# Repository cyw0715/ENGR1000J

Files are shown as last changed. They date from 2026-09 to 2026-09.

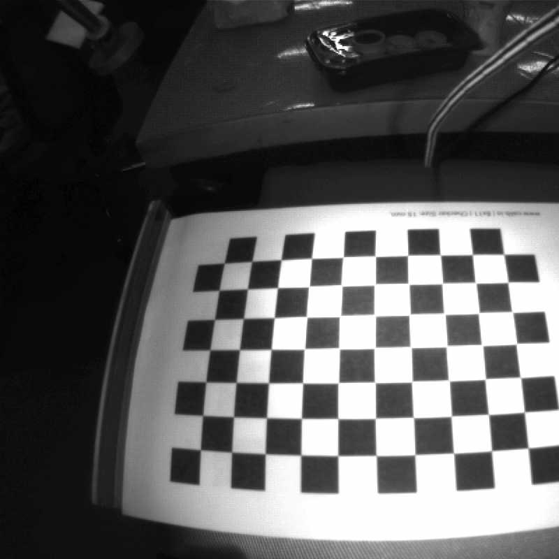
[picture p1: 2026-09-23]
project/wifi_test/calibration_runs/2026-08-04-fisheye-10x7-15mm/views/view_020.jpg

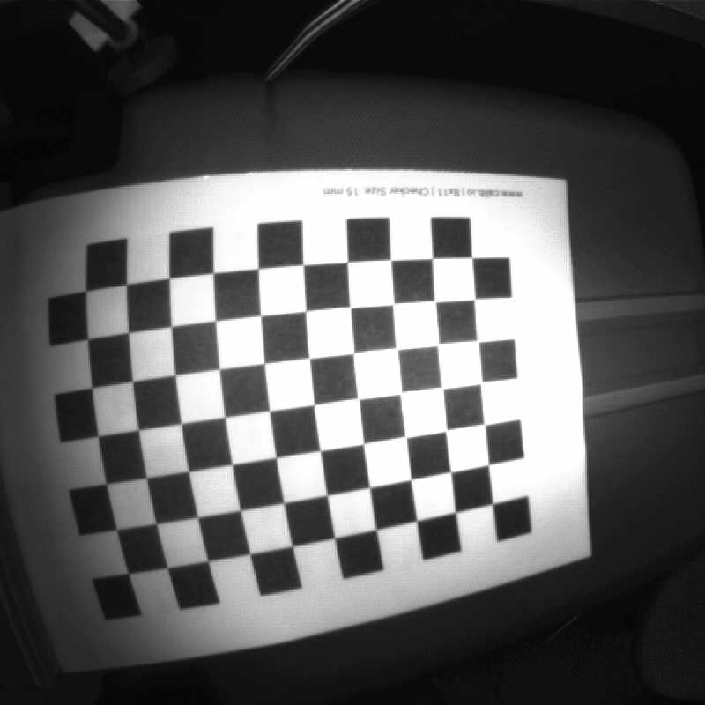
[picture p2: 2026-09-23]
project/wifi_test/calibration_runs/2026-08-04-fisheye-10x7-15mm/views/view_029.jpg

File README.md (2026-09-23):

# Mars Lander · Phase 2

四腿地形自适应火星降落器原型（ENGR1000 Phase 2）。下视相机 + IMU 做地形研究与姿态估计，四路直线推杆独立调节着陆平台。

## 仓库结构

| 路径 | 内容 |
|---|---|
| `project/` | 主工程：ESP32-P4 固件、Mega 执行器控制、PC 控制台、传感器测试 |
| `project/finalware/` | 当前部署固件快照与控制台（优先看这里） |
| `project/main/` | P4 主机相机/HTTP 固件 |
| `project/wifi_test/` | Wi-Fi 图传 / IMU 时间戳链路测试 |
| `project/usb_cdc_mega_test/` | Arduino Mega 四腿 VL53 闭环 + PS2 遥控 |
| `project/pc_viewer/` | Windows 控制台 `lander_console.py`、深度可视化 |
| `project/mechanical/` | 控制盒 CAD 生成脚本与 STEP/STL |
| `CAD/` | 外购件/结构 STEP 参考模型 |
| `docs/` | 交接文档、系统说明、接线总表、答辩 PPT、LaTeX |
| `experiments/` | MoGe 录屏深度实验 |
| `media/videos/` | 验证视频与控制台录屏（**不进 Git**，见 `.gitignore`） |

## 快速开始

### 固件（ESP-IDF v5.4+ / v5.5）

```bash
cd project          # 或 finalware/wifi_test 等子工程
idf.py set-target esp32p4
idf.py build
idf.py -p COMx flash monitor
```

### PC 控制台

```bash
cd project/pc_viewer
pip install -r requirements.txt
python lander_console.py
# 或 start_lander_console.bat
```

### Mega 执行器

Arduino IDE 打开 `project/usb_cdc_mega_test/faithful_remote_hybrid/faithful_remote_hybrid.ino` 烧录 Mega 2560。

## 安全边界（Stage 1）

- **Remote / CV Control**：遥控与 16 组预设，**不是**自动 CV 驱动腿。
- **IMU Control**：BNO085 姿态闭环，与 Remote 互斥。
- **相机 / 深度 / SR04 不得进入 Stage 1 腿指令路径**。
- `CV_CONTROL_VALIDATED = False` 仍为强制约束。

硬件映射、当前部署状态与调试步骤见 [`docs/HANDOVER.md`](docs/HANDOVER.md) 与 [`docs/PROJECT_SYSTEM_EXPLANATION.md`](docs/PROJECT_SYSTEM_EXPLANATION.md)。接线见 [`docs/火星降落器接线总表.md`](docs/火星降落器接线总表.md)。

## 硬件一览

| 层级 | 器件 | 职责 |
|---|---|---|
| 高层网关 | ESP32-P4 Function EV | 相机、BNO085、Wi-Fi/HTTP、USB Host、转发 Mega 指令 |
| 执行器 | Arduino Mega 2560 | 四路 VL53 位置闭环、PS2、电机、STOP/ESTOP |
| 传感器扩展 | TCA9548A | 四路同地址 VL53L1X |
| 惯性 | BNO085 | 姿态 |
| 相机 | OV5647 | 800×800 下视鱼眼 |
| 测距锚点 | HC-SR04 | 仅深度尺度研究输入 |

## 本地未入仓内容

验证视频、控制台录屏在 `media/videos/`；`build/`、`managed_components/`、Python venv、模型权重、Waveshare 示例包等可再生成，已由 `.gitignore` 排除。重新构建时 `idf.py` 会拉取 managed components。

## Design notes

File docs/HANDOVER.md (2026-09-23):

# Mars Lander Project — Engineering Handover

**Updated:** 2026-08-07 (CST)  
**Project root:** `E:\Chenyuewei\University\Freshman\summer\ENGR1000\p2\project`  
**Purpose:** preserve the hardware mapping, currently deployed firmware behavior, safety architecture, validation evidence, and next-stage commissioning sequence for the four-legged Mars landing platform.

---

## 1. System Purpose and Current Development Boundary

The project is a four-legged, terrain-adaptive Mars lander prototype. A downward-facing camera and an IMU support terrain research and attitude estimation; four independently controlled linear actuators provide landing-platform adjustment. The intended long-term behavior is to maintain a stable platform over unequal foot elevations.

The project is deliberately divided into two control stages:

```text
Stage 1 — deployed and controllable
  “CV Control” console mode = Remote owner, not automatic CV actuation.
  - faithful PS2 manual control and 16 source-program presets;
  - direct Console FL/FR/RL/RR absolute VL53 target entry;
  - Mega local four-leg position feedback and safety enforcement.

  “IMU Control” console mode = validated IMU attitude-control owner.
  - mutually exclusive with Remote;
  - retains the existing BNO085 attitude-control pathway.

Stage 2 — research only until separately validated
  Camera calibration → depth/terrain reconstruction → SR04 scale anchoring
  → four-foot relative elevation estimation → low-amplitude CV closed loop.

  `CV_CONTROL_VALIDATED = False` remains mandatory.
```

A computer-vision result, depth model, video stream, or SR04 reading must **not** enter a leg-command path in Stage 1.

---

## 2. Current Deployed Hardware State

### 2.1 Latest verified no-motion state

After the latest deployment and P4 recovery, repeated `/health` observations showed:

```text
P4 identity:  ESP32-P4 at 192.168.137.106
Mega state:   LOCKED
fault:        none
armed:        false
active:       false
target:       0,0,0,0
applied:      0,0,0,0
Mega RX line counter: increasing
```

Observed position feedback during the final no-motion verification was valid on all four channels:

```text
A1 = approximately 159–163 mm
A2 = approximately 94–96 mm
A3 = approximately 219–222 mm
A4 = approximately 143–145 mm
```

These values are installation-dependent measurements, not calibration constants.

### 2.2 Boards and links

| Layer | Hardware | Responsibility |
|---|---|---|
| High-level gateway | ESP32-P4 Function EV Board v1.3 | camera, BNO085, Wi-Fi/HTTP/TCP, USB Host, Mega command forwarding |
| Actuator controller | Arduino Mega 2560 + CH340 | four VL53 feedback loops, PS2 Remote behavior, motor outputs, STOP/ESTOP/watchdog |
| Sensor multiplexer | TCA9548A | isolates the four equal-address VL53L1X sensors |
| Inertial sensor | BNO085 | platform attitude for IMU mode |
| Camera | OV5647 | 800×800 downward-facing fisheye image stream |
| Range anchor | HC-SR04 on Mega | depth-scale research input only; never a Stage-1 leg target |
| PC application | Windows Console | mode selection, status display, Remote absolute-target entry, visualization and research tools |

### 2.3 USB identities

```text
P4 debug/programming interface:
  USB-Enhanced-SERIAL CH343, COM5
  VID:PID = 1A86:55D3

Mega downstream USB interface:
  CH340, VID:PID = 1A86:7523

Mega target signature:
  ATmega2560 = 1E9801
```

The P4 USB-A/OTG host connects to the Mega USB-B/CH340 device. P4-to-Mega commands must remain serialized through the single P4 transmit mutex.

---

## 3. Physical Four-Leg Mapping

The following mapping was established by bounded one-leg identification. It is authoritative.

```text
Mega A1 / TCA channel 0 / D22,D23,EN30 = RL (rear-left)
Mega A2 / TCA channel 1 / D24,D25,EN31 = RR (rear-right)
Mega A3 / TCA channel 2 / D26,D27,EN32 = FR (front-right)
Mega A4 / TCA channel 3 / D28,D29,EN33 = FL (front-left)

UI/solver order: FL, FR, RL, RR
Mega order:      A1, A2, A3, A4
Conversion:      FL→A4, FR→A3, RL→A1, RR→A2
```

Direction convention:

```text
EXTEND  → associated VL53 reading increases
RETRACT → associated VL53 reading decreases
```

Never pass a UI/solver array directly to Mega array positions without this remapping.

---

## 4. Mega Hybrid Firmware: Current Behavior

### 4.1 Source-faithful Remote controller

The hybrid firmware preserves the user-supplied Remote source as the behavioral reference. Immutable original reference:

```text
reference/111_1_original.ino
SHA256 = 1973c42c856dd61e18a53a6e8ca50d0e7503ce2a498bed8b9e75497d92f651f8
```

The deployed firmware preserves:

- PS2 wiring: DAT=D49, CMD=D47, CLK=D46, CS=D48;
- START toggle between `MANUAL` and `PRESET` selection modes;
- the original eight manual directional button mappings;
- the original 16 preset target vectors, values, and selection priority;
- three consecutive PS2 read failures before disconnect declaration;
- PS2 reconnect attempts every 2 s;
- preset tolerance of ±3 mm, two consecutive in-tolerance confirmations, and 30 s timeout.

The project-level automated contract compares the original and hybrid source for the presets, mappings, timing constants, reconnect behavior, and ownership boundary.

### 4.2 Ownership states

```text
LOCKED
  ALL_LOW; no PS2, Console, or IMU movement is permitted.

REMOTE_MANUAL / REMOTE_PRESET
  PS2 Remote is enabled after explicit `ARM REMOTE`.
  A Console absolute target temporarily suspends PS2 commands while it runs.

ARMED / ACTIVE
  IMU owner is enabled after explicit `ARM IMU`.
  PS2 Remote is suspended.

FAULT / ESTOP
  ALL_LOW; fault or emergency condition blocks normal movement.
```

Mode switching must stop the current owner before a new owner is armed. `STOP` and `ESTOP` bypass normal command authorization.

### 4.3 Active local safety functions

The following protections remain enabled and must not be removed during normal work:

```text
- four VL53 readings must be valid and fresh;
- maximum authoritative VL53 coordinate = 400 mm;
- current deployed lower coordinate = 0 mm;
- 2 s heartbeat timeout for host-owned Remote and IMU sessions;
- stale sensor timeout = 1200 ms;
- explicit STOP; latched ESTOP;
- hard all-output-low in LOCKED, FAULT, and ESTOP states;
- 120 ms break-before-make only when changing motor direction;
- non-blocking concurrent four-leg position regulation;
- full-group invalid target rejection, rather than silently altering an invalid command.
```

The lower coordinate was changed from 50 mm to 0 mm because a real valid sensor reading below 50 mm had caused `sensor_invalid_or_range`. This change does **not** remove sensor-validity, staleness, upper-limit, heartbeat, STOP, or ESTOP protection.

### 4.4 Remote protocol

```text
ARM REMOTE
HEARTBEAT <seq>
SET_REMOTE <seq> <FL> <FR> <RL> <RR>
STOP
ESTOP
STATUS
GET_DISTANCE
```

`SET_REMOTE` is in UI order `FL,FR,RL,RR` and uses direct absolute VL53 coordinates in the currently deployed range `[0,400]` mm. The Mega remaps this to physical A4,A3,A1,A2.

IMU commands remain separate:

```text
ARM IMU
HEARTBEAT <seq>
SET_DELTA <seq> <FL> <FR> <RL> <RR>
STOP
ESTOP
```

`SET_DELTA` is ARM-relative and still uses the bounded delta protocol. The Mega evaluates the resulting absolute target locally.

---

## 5. P4 Firmware and Network Interface

### 5.1 P4 production behavior

The ESP32-P4 production application provides:

```text
GET /board
  Board identity and current DHCP address.
  Required identity check: board == "ESP32-P4" and returned IP matches probe host.

GET /health
  P4 network, Mega, four-leg, SR04, Remote, and diagnostic status.

POST /cmd {"remote_arm": true}
  Forwards ARM REMOTE.

POST /cmd {"remote_set_absolute": true,
           "seq": N, "fl": ..., "fr": ..., "rl": ..., "rr": ...}
  Forwards SET_REMOTE with four absolute VL53 targets in [0,400] mm.

Existing IMU commands
  imu_arm, imu_set_delta, imu_heartbeat, imu_stop, imu_estop.
```

`/health.mega_imu` includes remote telemetry:

```text
remote_active
remote_source = ps2 | console | none
remote_preset = 0..15 or -1
remote_target_fl/fr/rl/rr
ps2_connected
remote_submode = manual | preset
```

### 5.2 Current network endpoints

| Endpoint | Function |
|---|---|
| TCP 5000 | JPEG frames: `[u32 little-endian length][JPEG bytes]` |
| TCP 5001 | JSONL latest BNO085 sample stream |
| HTTP `/board` | strict board identity and DHCP discovery |
| HTTP `/health` | P4/Mega/Remote/leg diagnostics |
| HTTP `/imu` | current IMU diagnostic state |

The current P4 address was last verified as `192.168.137.106`; do not hard-code it permanently. Use `/board` discovery.

### 5.3 CH340 session recovery

The production P4 firmware performs the proven sequence after CH340 opening:

```text
set_control_line_state(false, true)
wait 100 ms
set_control_line_state(true, true)
wait 6500 ms
begin Mega STATUS / GET_DISTANCE polling
```

It also reports `rx_byte_count` and `rx_line_count`. If the byte counter does not advance, the P4 is not receiving Mega application output; do not diagnose Console logic before resolving the transport/application layer.

---

## 6. Windows Console

Run the Console only with:

```text
pc_viewer\.venv_win\Scripts\python.exe
pc_viewer\.venv_win\Scripts\pythonw.exe
```

The UI has three modes:

```text
CV Control (Stage 1 Remote)
  - ARM button: ARM Remote
  - FL/FR/RL/RR absolute target entries: editable
  - Apply Remote target button: enabled
  - PS2 manual/preset remains the primary Remote interaction surface
  - CV, depth, video, and SR04 are preview/research-only inputs.

IMU Control
  - ARM button: ARM IMU
  - Remote target entries: read-only
  - Remote Apply button: disabled
  - P4 TCP 5001 attitude stream is required by the IMU loop itself.

Locked
  - Remote entries: read-only
  - Remote Apply: disabled
  - ARM: disabled.
```

Remote command availability does not depend on SR04, camera TCP 5000, depth model load, CV capture count, CV candidate age, or `CV_CONTROL_VALIDATED`. It does depend on P4/Mega communication, valid four-leg feedback, owner state, and hard safety status.

Before launching a new Console instance, close stale `lander_console.py` processes. Two stale processes previously re-armed a Remote session after P4 recovery; this was resolved by issuing `STOP`, confirming `LOCKED`, and closing both processes.

---

## 7. Camera, IMU, SR04, and Vision Research

### 7.1 Camera calibration

The replacement camera is an 800×800 fisheye camera. The accepted calibration result is:

```text
Calibration set: 36 views
Board: 11×8 squares, 10×7 inner corners, 15 mm square size
RMS reprojection error: 0.717 px
Mean reprojection error: 0.562 px
Maximum reprojection error: 1.947 px
Accepted for geometry: true

K ≈ [[638.075, 0, 613.459],
     [0, 636.365, 452.471],
     [0,   0,       1   ]]
D ≈ [-0.06099, 0.09688, -0.14361, 0.06626]
```

Results are stored under:

```text
wifi_test/calibration_runs/2026-08-04-fisheye-10x7-15mm/
```

External-pose collection reached 20/20 usable samples:

```text
Mean reprojection error: 0.345 px
Maximum reprojection error: 0.366 px
Camera-to-board-plane distance: 354.73 mm
Optical-axis inclination: 3.66 degrees
```

The platform front/back 180° ambiguity remains unresolved. Do not use this pose for control orientation until that ambiguity is eliminated.

### 7.2 SR04 role

The HC-SR04 is wired to Mega:

```text
TRIG = D53
ECHO = D52 / PB1 / PCINT1
```

It is a scale anchor for depth research only. A stable window requires recent independent samples, a median, minimum count, and spread/MAD checks. Its accepted use is:

\[
\mathrm{scale}=
\frac{\mathrm{stable\ SR04\ median}}
{\mathrm{model\ depth\ median\ in\ principal-point\ ROI}},
\qquad
D_{\mathrm{corrected}}=\mathrm{scale}\cdot D_{\mathrm{model}}.
\]

If the SR04 stability test fails, use `metric_source=model_only`; do not reuse an old scale anchor. SR04 distance must never be converted directly into a common leg extension.

### 7.3 CV terrain semantics

Future CV control may use only relative terrain differences across the four predicted foot regions:

\[
\delta_i=L_i-\frac{1}{4}\sum_{j=1}^{4}L_j,
\qquad
\sum_i\delta_i=0.
\]

The current research constraints are:

```text
- each relative correction limited to ±100 mm;
- boundary handling uses one common scale factor, never independent clipping;
- a common terrain-height offset must not change the command;
- NaN/unobservable foot regions reject the plan;
- vision output remains preview-only until physical plane/step validation is complete.
```

A real scale-correction script processed 16 valid anchored frames with an observed scale approximately 0.526–0.607, but the intended 30-frame acquisition was not completed because TCP 5000 permits one client. Do not claim complete 30-frame acceptance yet.

---

## 8. Firmware Artifacts and Build Evidence

### Mega hybrid source

```text
usb_cdc_mega_test/faithful_remote_hybrid/
  faithful_remote_hybrid/faithful_remote_hybrid.ino
  reference/111_1_original.ino
  test_faithful_remote_contract.py
```

Latest range-0-to-400 Mega application image:

```text
SHA256 = da51089c186d3912c7e228fabce591849e693fdf4ee7221c5b981866abb54076
ATmega2560 application payload = 22,380 bytes
Pages written = 88
Verification = every page read back after write
```

### P4 production source

```text
wifi_test/main/main.c
wifi_test/main/mega_sr04.c
wifi_test/main/mega_sr04.h
```

Current build passed ESP-IDF v5.4 and generated `wifi_test.bin` with approximately 21% free application partition space. P4 flashing verified the bootloader, partition table, and application image with `Hash of data verified` for each region.

### Tests last run successfully

```text
PC Console + terrain/control suite: 124 tests
Faithful Remote source contract: 9 tests
P4 protocol contract: 12 tests
Legacy Mega controller contract: 10 tests
```

---

## 9. Safe Commissioning Sequence

Use the following sequence after any firmware, cable, or mechanical change:

1. Confirm no stale Console process is running.
2. Read `/board`; verify `board=ESP32-P4` and the current DHCP address.
3. Read `/health` repeatedly. Require increasing Mega RX counters, `LOCKED`, `fault=none`, valid A1--A4, zero target, and zero applied values.
4. If any fault occurs, send `STOP`; do not arm around a fault.
5. For a first Remote test, arm Remote with no button pressed and no Console target.
6. Confirm `REMOTE_MANUAL` or `REMOTE_PRESET`, `remote_active=false`, and no motor output.
7. Perform a same-current-value Console target or a verified no-motion preset selection before requesting motion.
8. Test one small 2--3 mm change at a time; then STOP and verify `LOCKED`.
9. Commission PS2 manual and preset behavior separately from IMU behavior.
10. Commission IMU only after Remote STOP, explicit IMU ARM, and live TCP 5001 attitude verification.

Never start a movement experiment by testing all four legs, a large preset, or an unverified CV output.

---

## 10. Open Work

1. Diagnose the full PS2 electrical connection if `ps2_connected=false`; a disconnected Remote must remain harmless.
2. Complete Stage-1 physical verification of selected source presets and direct Console absolute targets using small, supervised movements.
3. Re-confirm the IMU closed-loop behavior after the Hybrid Mega firmware change; preserve the previously accepted installation transform and PID semantics.
4. Resolve the external-pose front/back ambiguity.
5. Complete physical flat-plane and 10/20/30/50 mm step validation for the depth pipeline.
6. Complete a dedicated 30-frame SR04-anchored depth acquisition after releasing TCP 5000 from other clients.
7. Do not enable automatic CV leg actuation until all calibration, terrain, relative-delta, and staged hardware acceptance gates are documented as passed.

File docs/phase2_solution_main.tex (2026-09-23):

\documentclass{engr1000j-s2}

\usepackage{tabularx}
\usepackage{lastpage}
\usepackage{listings}
\usepackage{amsmath}
\usepackage{amssymb}
\usepackage{enumitem}

\usepackage{tocloft}

% spacing between numbering and title
\renewcommand{\cftsecaftersnum}{\hspace{1em}}
\renewcommand{\cftsubsecaftersnum}{\hspace{1em}}
\renewcommand{\cftsubsubsecaftersnum}{\hspace{1em}}

% indentation for hierarchy
\setlength{\cftsecindent}{0em}
\setlength{\cftsubsecindent}{2em}
\setlength{\cftsubsubsecindent}{4em}

% dot spacing
\renewcommand{\cftdotsep}{1}

\hypersetup{
  hidelinks,
  pdftitle={Mars Explorer Phase Two Report},
  pdfauthor={Group 5: Six Gentlemen}
}

\lstdefinestyle{appendixcode}{
  basicstyle=\ttfamily\scriptsize,
  breaklines=true,
  breakatwhitespace=false,
  columns=fullflexible,
  keepspaces=true,
  showstringspaces=false,
  frame=single,
  xleftmargin=0pt,
  xrightmargin=0pt
}

\newcommand{\statusdone}{\textbf{Completed}}
\newcommand{\statusprogress}{\textbf{In Progress}}
\newcommand{\statusplanned}{\textbf{Planned}}

\begin{document}

  
  \newline
  \newline
  \textbf{\Large ENGR1000J Introduction to Engineering, Summer 2026}\\[0.5em]
  \textbf{{\Large 2026.08.08}}

  \begin{center}
    \begin{minipage}{0.45\textwidth}
      
    \end{minipage}\hfill
    \begin{minipage}{0.45\textwidth}
      \textbf{\Large Group 5: Six Gentlemen}
    \end{minipage}\\[0.2em]
  \end{center}

  \noindent
  {\color{gray!30}\rule{\textwidth}{0.1pt}}

  {\Huge Self-Stabilizing Landing Platform}

  \begin{center}
    
  \end{center}

  \hspace{1em}

  {\Large
  Chen Yuewei\par\vspace{-10pt}
  Sun Andong\par\vspace{-10pt}
  Sun Yongjian\par\vspace{-10pt}
  Cui Yukun\par\vspace{-10pt}
  Ding Junyuan\par\vspace{-10pt}
  Ge Chengzhi\par\vspace{-10pt}
  }

  \newpage
  \pagestyle{mystyle}

 \section{Abstract}
  \phantomsection

Reliable landing is essential for planetary exploration because an inclined landing platform may reduce antenna alignment, decrease solar-panel efficiency, and create unstable conditions for rover deployment. Rough and uneven Martian terrain can cause the landing legs to contact the surface at different heights, leaving the platform tilted even after a safe touchdown. This project aimed to develop a self-stabilizing landing platform that could actively correct its attitude after landing and provide a more stable base for subsequent mission operations. The proposed prototype used a four-leg aluminum structure with independently adjustable linear actuators. An OV5647 camera was used for terrain imaging, a BNO085 inertial measurement unit measured the platform attitude, and four VL53L0X time-of-flight sensors monitored the extension of the landing legs. An ESP32-P4 and ESP-C6 processing unit calculated the required leg-length adjustments, while an Arduino Mega 2560 controlled the actuators through the motor-driving system. After touchdown, the platform measured its inclination and leg positions, determined which legs required extension or retraction, and repeatedly performed sensing, calculation, and actuation until the residual tilt was reduced. Physical testing showed that the prototype achieved an average final tilt angle of \(2.61^\circ\), below the design limit of \(5.0^\circ\). It also maintained a descent speed of \(5.2~\mathrm{cm/s}\), supported a payload of at least \(16~\mathrm{kg}\), and completed 19 of 20 trials successfully, corresponding to a success rate of \(95\%\). These results demonstrate that independent leg adjustment combined with closed-loop feedback can effectively reduce terrain-induced platform inclination. Although the current prototype was tested only under Earth-based laboratory conditions, the project verified the feasibility of active post-touchdown leveling. Further development of this technology could improve the reliability of planetary landers, protect onboard instruments, support safer rover deployment, and enable future exploration missions to operate on a wider range of uneven terrain.

\hspace{1em}

\section{Acknowledgments}
\phantomsection

The team would like to thank the ENGR1000J instructors, teaching assistants, and course support staff for their guidance throughout Phase Two. Their lectures, laboratory sessions, office-hour feedback, and project regulations provided the technical framework for the design, fabrication, testing, and reporting process.

The team also acknowledges the use of Codex and Gemini as writing and formatting assistance tools, and Image2 and Nano Banana as AI image-generation tools. Codex and Gemini were used to help organize report sections, refine English wording, structure LaTeX tables, and check whether report requirements were clearly represented. Image2 and Nano Banana were used to support image generation for report visuals. All technical claims, design descriptions, material choices, generated images, and test results were reviewed and confirmed by the team before inclusion in the final report.

  \newpage
  \tableofcontents
  \thispagestyle{mystyle}
  \newpage

\section{Problem}
\label{sec:problem}

The surface of Mars presents a major challenge to the safe landing and subsequent operation of robotic exploration systems. Martian terrain contains rocks, slopes, depressions, loose soil, and other irregular surface features. Observations from NASA's surface missions show that steep slopes, rocks, and sand can significantly restrict robotic operations and require mission teams to avoid hazardous regions \cite{nasa_curiosity_climb}. At the scale of a landing platform, these irregularities may cause its supporting legs to contact the surface at different elevations. Consequently, a spacecraft may complete its descent without structural damage but remain tilted after touchdown.

Platform inclination can affect several important mission functions. Communication antennas and solar panels depend on suitable orientation to achieve effective signal transmission and power generation. A tilted deck may also reduce the stability of scientific instruments and create unsafe conditions for rover release. These consequences are especially important because planetary missions operate with limited energy, restricted communication opportunities, and little possibility of physical repair. A landing attitude that would be only a minor inconvenience on Earth may therefore reduce scientific return or threaten the operation of an entire Mars mission.

Terrain slope is already treated as an important engineering constraint during landing-site evaluation. NASA's engineering guidance for the Mars Science Laboratory classified surface slopes below \(5^\circ\) as low, slopes between \(5^\circ\) and \(15^\circ\) as moderate, and slopes above \(15^\circ\) as high \cite{msl_engineering_guide}. This classification demonstrates that relatively small differences in surface geometry can influence landing and surface-operation decisions. However, orbital images and pre-landing measurements cannot always identify every rock or height variation beneath an individual landing leg. Even a region considered generally safe may therefore produce unequal contact conditions at the final touchdown points.

Previous engineering approaches have addressed parts of this problem. Passive landing structures and shock absorbers can reduce touchdown impact and protect the lander from excessive loads \cite{pham2013}. More recent missions have also used hazard-detection and terrain-relative navigation technologies. For example, the Mars 2020 landing system compared descent images with stored terrain maps and could redirect the vehicle toward a safer area \cite{nasa_trn2020}. Lidar-based hazard-detection systems have similarly been investigated for planetary landing applications \cite{huang2024}. These methods improve landing safety by reducing impact or avoiding major hazards before touchdown.

Nevertheless, these approaches do not completely address the remaining static inclination after ground contact. Passive dampers absorb energy but do not normally correct unequal final support heights. Pre-landing hazard avoidance selects a safer region, but its effectiveness is limited by sensing resolution, landing-position uncertainty, and small local surface features. The unresolved problem therefore affects spacecraft designers, mission operators, scientific payload teams, and rover-deployment systems: a lander may survive touchdown but still lack a sufficiently stable and level operating platform.

\medskip
\noindent\textbf{In summary, the most important unresolved problems are:}

\begin{enumerate}
    \item Unequal landing-leg contact heights caused by rocks, slopes, and surface depressions;
    \item Residual platform tilt that may reduce communication, power generation, instrument stability, and rover-deployment safety;
    \item Limited ability of passive landing systems to correct static inclination after touchdown;
    \item Incomplete protection from small terrain variations despite pre-landing hazard detection and landing-site selection.
\end{enumerate}

\section{Needs}
\label{sec:needs}

To address the problems caused by uneven landing-leg contact and residual platform tilt, the landing platform requires an active system that can detect its condition after touchdown and respond to local terrain variations. The system must not depend only on passive shock absorption or pre-landing hazard avoidance, because these methods cannot fully compensate for small differences in the final contact heights of the landing legs. Instead, the platform must combine sensing, computation, mechanical adjustment, and feedback control in one integrated process.

The principal engineering needs of the project are:

\begin{itemize}
    \item \textbf{Terrain and attitude sensing methods to detect uneven ground contact, local height differences, and residual platform inclination after touchdown.}

    \item \textbf{Four independently adjustable landing legs capable of extending or retracting to compensate for different ground-contact heights.}

    \item \textbf{A closed-loop control method that repeatedly measures the platform attitude, calculates the required leg-length changes, and commands the actuators until the tilt is reduced below the specified limit.}

    \item \textbf{A sufficiently strong and stable supporting structure that can carry a payload of at least \(15~\mathrm{kg}\) while maintaining reliable actuator motion and sensor alignment.}

    \item \textbf{System integration and experimental validation methods that evaluate tilt reduction, descent speed, payload capacity, and leveling success rate under different uneven-terrain conditions.}
\end{itemize}

To satisfy the sensing requirement, the platform needs both environmental and internal measurements. Terrain imaging is required to observe the landing surface, while an inertial measurement unit is needed to determine the orientation of the main platform. Additional distance sensors are required to monitor the extension of each adjustable leg. In the proposed system, these functions are provided by an OV5647 camera, a BNO085 inertial measurement unit, and four VL53L0X time-of-flight sensors.

The mechanical system requires four miniature linear actuators so that each landing point can be adjusted independently. Independent control is necessary because the height error at one leg may differ from that at the other three legs. The actuators must also provide sufficient force to support the platform and its payload without uncontrolled retraction or excessive structural deformation.

A processing and control system is required to convert sensor measurements into physical corrections. The ESP32-P4 and ESP-C6 processing unit must analyze the sensing information and calculate the required change in each leg length. The Arduino Mega 2560 must then control the actuators through the motor-driving system. After each movement, the platform attitude must be measured again so that the remaining error can be corrected.

Finally, the completed system must be tested against measurable performance requirements. The final tilt angle should be below \(5.0^\circ\), the payload capacity should be at least \(15~\mathrm{kg}\), the descent speed should be approximately \(5~\mathrm{cm/s}\), and the landing and leveling process should achieve a success rate of at least \(90\%\). Meeting these needs would provide a stable post-touchdown platform for communication equipment, solar panels, scientific instruments, and rover-deployment systems.

\newpage

\section{Solution}

\begin{enumerate}
    \item \textbf{A four-corner adaptive landing platform} with one independently controlled linear actuator at each landing corner, allowing the support plane to be adjusted after touchdown on uneven terrain.
    \item \textbf{A distributed sensing and control architecture} combining four VL53L1X position sensors, a TCA9548A multiplexer, an Arduino Mega 2560 real-time actuator controller, an ESP32-P4 communication gateway, a BNO085 IMU, an OV5647 camera, and an HC-SR04 range sensor.
    \item \textbf{A completed Stage-1 terrain-elevation control mode} that converts a calibrated elevation map of the four landing-foot regions into coordinated differential leg-length targets.
    \item \textbf{A mutually exclusive IMU attitude-control mode} that uses measured platform roll and pitch to generate coordinated differential leg corrections.
    \item \textbf{A layered safety architecture} incorporating explicit arming, command ownership, local position feedback, sensor freshness checks, heartbeat supervision, STOP, ESTOP, travel limits, and all-output-low fault behavior.
\end{enumerate}

The proposed solution is a terrain-adaptive Mars landing platform intended to reduce post-touchdown tilt when the four landing feet contact terrain of unequal elevation. The platform is approximately $200\,\mathrm{mm}\times200\,\mathrm{mm}$, with one independently driven linear actuator at each corner. A rigid landing configuration transfers local terrain height differences directly into platform roll and pitch; consequently, it can degrade payload stability, camera pointing, and the available actuator travel margin. The proposed system instead treats the four leg positions as independently regulated variables and uses their coordinated motion to alter the support plane formed by the landing feet.

The physical actuators are designated FL, FR, RL, and RR. Their mapping to the Mega controller is fixed as
\[
\mathrm{FL}\rightarrow A4,\qquad
\mathrm{FR}\rightarrow A3,\qquad
\mathrm{RL}\rightarrow A1,\qquad
\mathrm{RR}\rightarrow A2.
\]
This mapping is essential because the geometric solver uses the order FL--FR--RL--RR whereas the electrical controller uses A1--A4. Each actuator has a dedicated VL53L1X time-of-flight sensor. The four equal-address sensors are isolated through a TCA9548A I$^2$C multiplexer, enabling the Mega to acquire independent position feedback for every leg. The verified direction convention is
\[
\text{EXTEND}\Rightarrow d_i\ \text{increases},
\qquad
\text{RETRACT}\Rightarrow d_i\ \text{decreases},
\]
where $d_i$ is the local VL53 coordinate of actuator $i$.

For every requested target $d_{i,\mathrm{target}}$, the Mega calculates the local position error
\[
e_i=d_{i,\mathrm{target}}-d_{i,\mathrm{measured}}.
\]
A positive error commands extension and a negative error commands retraction. The actuator output is disabled after the target is reached within the specified tolerance. This local feedback loop is executed on the Mega rather than on the PC, so a delayed Wi-Fi packet, a frozen camera frame, or a Windows application failure cannot remove the fundamental position-feedback and stop functions. Direction reversal includes a $120\,\mathrm{ms}$ break-before-make interval, preventing opposing motor-drive states from being applied simultaneously.

\subsection*{Stage-1 Elevation-Map Landing-Leg Control}

Stage~1 implements the completed terrain-adaptive landing controller. The OV5647 fisheye camera provides an elevation map of the landing area, while the calibrated camera geometry projects the four predicted foot-contact regions into that map. The controller samples a robust local elevation $h_i$ for each foot region $i\in\{\mathrm{FL},\mathrm{FR},\mathrm{RL},\mathrm{RR}\}$. Invalid pixels, regions outside the valid depth field, and inconsistent local estimates are rejected before target generation. The HC-SR04 provides the global millimetre scale anchor for the reconstructed elevation field; it is not used as an independent per-leg height sensor.

The controller removes the common elevation component so that it commands only support-plane compensation rather than an arbitrary collective translation. With
\[
\bar h=\frac{1}{4}\sum_{j=1}^{4}h_j,
\qquad
\Delta h_i=h_i-\bar h,
\qquad
\sum_{i=1}^{4}\Delta h_i=0,
\]
the required leg-length correction is generated as
\[
L_{i,\mathrm{target}}=L_{i,0}+k_h\Delta h_i,
\]
where $L_{i,0}$ is the established landing reference length and $k_h$ is the calibrated sign and scale factor relating terrain elevation to actuator length. Thus, a relative terrain-height change modifies the landing-leg configuration while preserving the mean commanded length. The Console and P4 remap the geometric order FL--FR--RL--RR to the fixed Mega order A4--A3--A1--A2 before sending the four targets to the common Mega position-control routine.

Each candidate correction is constrained to the approved differential travel envelope $|\Delta L_i|\leq100\,\mathrm{mm}$. If a candidate would cross a leg travel boundary, all four differential corrections are reduced by one common scale factor rather than clipping individual legs. This preserves the intended support-plane orientation and the zero-sum condition. The Mega then closes the four local VL53L1X feedback loops independently; it stops each output on target, stale feedback, invalid feedback, timeout, STOP, or ESTOP. Consequently, the elevation map selects the coordinated target geometry, while the hardware-proven Mega loop remains responsible for final actuator positioning and non-motion safety.

The Stage-1 result is a complete path from camera-derived terrain elevations to bounded four-leg target lengths. It compensates the relative elevation differences across the four foot regions and therefore reduces predicted post-touchdown roll and pitch without treating the absolute terrain range as an individual leg command.

\subsection*{Stage-2 IMU Attitude-Control Solution}

The second control owner is the IMU mode. It is mutually exclusive with Stage-1 elevation-map control: switching modes first issues STOP to the active owner, clears pending targets, and requires a new explicit ARM action. The BNO085 provides platform attitude. Its installation-frame transformation converts the sensor reading into platform roll and pitch, which are then used to generate coordinated differential leg corrections. The target condition is approximately
\[
|\phi_{\mathrm{platform}}|\leq1^\circ,
\qquad
|\theta_{\mathrm{platform}}|\leq1^\circ.
\]

IMU control changes opposing corners in opposite directions where appropriate, producing a change in support-plane orientation rather than an arbitrary common vertical displacement. The existing IMU pathway retains its validated outer attitude correction, inner position regulation, bounded target update rate, and Mega-side local safety checks. It is therefore an automatic leveling mode based on measured inertial state, complementary to the completed Stage-1 terrain-elevation controller.

\subsection*{Safety and Communication Solution}

The lander uses a layered authority model. The PC Console provides user interaction, status visualization, and high-level mode requests. The ESP32-P4 handles Wi-Fi, the camera and IMU interfaces, USB Host communication, and a single serialized command path to the Mega CH340 interface. The Mega remains the actuator safety authority. It implements the states \texttt{LOCKED}, \texttt{STAGE1\_ELEVATION}, \texttt{IMU\_ACTIVE}, \texttt{FAULT}, and \texttt{ESTOP}.

In \texttt{LOCKED}, \texttt{FAULT}, and \texttt{ESTOP}, all motor enable and direction outputs are low. Host-owned sessions require a heartbeat; if no valid heartbeat arrives within two seconds, the Mega stops the outputs. Each VL53 reading must be valid and newer than the sensor freshness threshold. The controller also rejects targets above the $400\,\mathrm{mm}$ upper limit. STOP and ESTOP bypass normal motion authorization. Consequently, the proposed lander does not rely on correct PC software, continuous Wi-Fi, or valid computer vision to preserve a safe non-motion state.

\newpage

\section{Objectives}

The seven objectives below correspond one-to-one with Tasks~1--7 in Section~\ref{sec:tasks}. Each objective defines the intended deliverable and the verification focus of its corresponding task.

\textbf{Objective 1 (Task 1): Design and fabricate the aluminum frame.}

Develop a rigid 2020L aluminum-extrusion support frame that provides the required height, stiffness, and attachment points for the four-point suspension and landing-platform test system. Verify that the frame can safely support the platform, payload, winch assemblies, and associated wiring without unacceptable deformation or loss of alignment.

\textbf{Objective 2 (Task 2): Design and control the four-winch descent system.}

Design the four-motor winch mechanism and its L298N-based control system so that the suspended platform can descend and be retrieved with coordinated cable motion. Establish start/stop, direction-reversal, braking, and individual PWM compensation behavior, then verify a controlled descent speed of approximately $5~\mathrm{cm/s}$.

\textbf{Objective 3 (Task 3): Design and fabricate the adjustable landing platform.}

Build the $300~\mathrm{mm}\times300~\mathrm{mm}$ acrylic landing platform, four angled linear-actuator legs, reinforced brackets, articulated feet, and leg-displacement sensing mounts. The completed structure must provide independent FL, FR, RL, and RR adjustment, preserve the geometric-to-electrical leg mapping, and support at least $15~\mathrm{kg}$ while maintaining mechanical stability and sensor alignment.

\textbf{Objective 4 (Task 4): Implement computer-vision-based terrain detection.}

Use the calibrated OV5647 fisheye camera to construct an elevation map of the landing area and estimate robust relative elevations in the four projected foot-contact regions. Use the HC-SR04 only as a global millimetre scale anchor, reject invalid terrain regions, and transform valid relative elevations into a zero-sum, travel-bounded four-leg compensation vector rather than four independent absolute-height commands.

\textbf{Objective 5 (Task 5): Implement IMU-based automatic leveling.}

Use the BNO085 to measure platform roll and pitch after touchdown and implement a mutually exclusive automatic leveling mode that commands coordinated differential leg corrections. Verify that the controller uses bounded updates, the Mega local position-feedback loop, and STOP/ESTOP protection to reduce residual platform tilt toward the $5.0^\circ$ design limit without arbitrary collective leg motion.

\textbf{Objective 6 (Task 6): Design and fabricate repeatable simulated terrain.}

Create laboratory terrain fixtures with known slopes, steps, and unequal landing-foot elevations that reproduce the local-height disturbances expected during touchdown. The terrain must be stable, repeatable, compatible with the articulated feet, and sufficiently varied to evaluate both elevation-map compensation and IMU-based leveling.

\textbf{Objective 7 (Task 7): Integrate and validate the complete landing system.}

Integrate the aluminum frame, winch system, landing platform, terrain sensing, IMU, controllers, communication path, and simulated terrain into one testable prototype. Validate system-level performance through repeated landing trials, including final tilt, descent speed, payload capacity, sensor and actuator safety behavior, and a leveling success rate of at least $90\%$.

\newpage

\section{Tasks}
\label{sec:tasks}

\subsection{Overview of Project Tasks and Workflow}

\newpage

\subsection{Task 1: Aluminum Frame Design and Fabrication}

\subsubsection{Structural Requirement Analysis}

\subsubsection{Aluminum Frame Design and Fabrication}

\newpage

\subsection{Task 2: Winch Motor System Design and Control}

\subsubsection{Winch Mechanism Design}

\subsubsection{Winch Motor Control}

\newpage

\subsection{Task 3: Landing Platform Design and Fabrication}

\subsubsection{Platform Structural Design and Assembly}

The landing platform was designed as a lightweight and modular mechanical structure that integrates four independently adjustable landing legs, the electronic control hardware, and the interfaces required for the external descent system. The main platform was fabricated from a \(5~\mathrm{mm}\)-thick acrylic plate with an overall envelope of \(300~\mathrm{mm}\times300~\mathrm{mm}\). Rather than using the complete square plate, the four corner regions were removed, leaving a \(200~\mathrm{mm}\times200~\mathrm{mm}\) central area with four \(100~\mathrm{mm}\)-wide extensions centered on its sides. These extensions provided dedicated locations for the suspension eye nuts and allowed the four suspension points to be aligned with the winch system mounted on the external aluminum frame.

The acrylic plate also served as a modular mounting board for the electronic components. A regular array of \(4~\mathrm{mm}\)-diameter mounting holes was fabricated at \(20~\mathrm{mm}\) intervals across the usable platform area. The resulting perforated-board structure allowed the Arduino, sensor interfaces, motor-control electronics, wiring, and other modules to be secured using cable ties without requiring a dedicated mounting hole pattern for every component. This arrangement simplified assembly and allowed the positions of individual modules to be adjusted during system integration. It also made components easier to remove or replace when modifications were required.

Four linear actuators formed the adjustable landing legs. Each actuator was mounted at one corner of the acrylic platform using a customized 3D-printed PLA bracket. The mounting geometry was modeled in SolidWorks so that each actuator was installed at an angle of \(30^\circ\) from the vertical direction. Integrating this angle directly into the bracket geometry ensured that the four legs could be assembled with a consistent orientation without manually setting the angle during installation. The outward inclination also increased the spacing between the four ground-contact points relative to the size of the central platform while providing sufficient clearance for actuator extension.

Additional customized PLA components were designed for the displacement-measurement system installed on each landing leg. A VL53L0X Time-of-Flight sensor and a matte target plate were mounted on the two relatively moving sections of each actuator using separate 3D-printed holders. As the actuator extended or retracted, the relative distance between the sensor and the target changed accordingly. The target plate provided a defined measurement surface, allowing the measured distance to represent the change in actuator extension. This mechanical arrangement therefore integrated the leg-length measurement hardware directly into the actuator structure without modifying the actuator itself.

Each actuator was also equipped with a 3D-printed articulated foot at its lower end. The foot was connected through a single-axis rotating joint rather than being rigidly fixed to the actuator rod. This allowed the contact surface to rotate relative to the leg and accommodate different local surface angles when the platform landed on uneven terrain. The articulated connection reduced the requirement for the actuator axis to remain perpendicular to the terrain at every landing point and provided a larger and more adaptable contact surface than the actuator rod alone.

The structural design of the actuator brackets was revised during fabrication after an initial load-bearing failure. The first version of the PLA actuator mounting bracket was printed with a \(15\%\) infill ratio. Because this bracket transferred the landing-leg load directly to the acrylic platform, the relatively low-density printed structure was insufficient for the required load and fractured during testing. The bracket was subsequently thickened and reprinted with \(100\%\) infill. The reinforced version was then used for the final assembly. This modification demonstrated that the actuator mounting brackets were load-bearing structural components and therefore required substantially greater strength than non-load-bearing sensor holders.

The complete structure was assembled in stages. First, the external 2020L aluminum extrusion frame was constructed and the four-motor winch system was installed at the top of the frame. In parallel, the four linear actuators and their reinforced 3D-printed mounting brackets were attached to the corners of the acrylic platform. The sensor holders, matte target plates, and articulated feet were then installed on the corresponding sections of each landing leg. The electronic modules were positioned on the perforated acrylic plate and secured through the mounting holes using cable ties. Finally, the suspension eye nuts on the four side extensions of the platform were connected to the fishing-line suspension system and aligned with the four winches above. This modular assembly procedure allowed the landing platform and the external descent frame to be constructed and tested separately before being integrated into the complete landing system.

\newpage

\subsection{Task 4: Computer Vision Based Terrain Detection}
\label{task:cv-terrain}

\subsubsection{Fisheye Calibration and Platform Coordinate System}

Task~4 developed the terrain-observation path used to estimate the relative elevation at the four expected landing-foot regions. The downward-looking OV5647 camera operated at $800\times800$ pixels. Because its fisheye lens introduces substantial distortion away from the image center, the camera was calibrated with an $11\times8$ square checkerboard containing $10\times7$ inner corners and $15~\mathrm{mm}$ squares. Thirty-six valid calibration views were retained. The OpenCV fisheye solution achieved a mean reprojection error of $0.562$ pixels and an RMS error of $0.717$ pixels, providing the intrinsic matrix and distortion coefficients used in terrain projection.

A camera-to-platform transformation was then measured with the checkerboard fixed in the platform coordinate frame. Twenty pose samples established the rigid transformation. The camera center was approximately $354.7~\mathrm{mm}$ above the board reference plane, and the optical-axis tilt relative to the board normal was $3.66^\circ$. An asymmetric front marker verified the axis convention: platform $+x$ points right, platform $+y$ points forward, and platform $+z$ points upward. This verification is essential because a geometrically valid image measurement must still be associated with the correct physical landing leg.

\subsubsection{Depth-Map Construction and Scale Anchoring}

The PC receives the downward camera stream, rejects frames with insufficient scene structure, and estimates dense depth maps from accepted images. A metric-depth estimate and a relative-depth estimate are fused. To reduce sensitivity to JPEG artifacts, motion blur, and isolated inference errors, the software captures thirty valid depth maps, ranks them by consistency, and aggregates the best ten into a stable point cloud. The accepted fisheye intrinsics and camera-to-platform transformation then map valid samples into the platform coordinate system.

The HC-SR04 sensor is mounted beside the camera and is used only as a global millimetre-scale anchor. Its reading is accepted only when it is valid, fresh, within $20$--$4000~\mathrm{mm}$, and consistent with the depth values near the optical center. One accepted range measurement scales the complete depth map; it is not used as an individual-leg height sensor. This preserves the required distinction between a global distance reference and the four spatial terrain observations needed to determine support-plane shape.

\subsubsection{Four-Foot Terrain Sampling and Differential Command}

For each projected foot-contact region $i\in\{\mathrm{FL},\mathrm{FR},\mathrm{RL},\mathrm{RR}\}$, the transformed point cloud is sampled to obtain a robust local terrain elevation $h_i$. A candidate is rejected if a foot region is not visible, contains invalid depth, or gives no mechanically safe contact solution. Partially visible terrain is retained only as a diagnostic preview and is never allowed to produce a motion command.

The controller removes the common elevation component before target generation:
\[
\bar h=\frac{1}{4}\sum_{j=1}^{4}h_j,
\qquad
\Delta h_i=h_i-\bar h,
\qquad
\sum_{i=1}^{4}\Delta h_i=0.
\]
This zero-sum condition ensures that a uniform shift in terrain range does not command an arbitrary collective extension or retraction. The resulting vector is generated in geometric order FL--FR--RL--RR and mapped to Mega channels A4--A3--A1--A2. Each relative correction is limited to $\pm100~\mathrm{mm}$. If a proposed value would exceed the available $50$--$400~\mathrm{mm}$ VL53 range, all four entries are reduced by one common scale factor; independent clipping is not used because it would distort the compensated support-plane shape. Integer rounding is balanced again so the final four-leg command remains exactly zero-sum.

\subsubsection{Task Outcome}

Task~4 produced a safety-gated pipeline from OV5647 imagery to a bounded four-leg terrain-compensation vector: calibrated image $\rightarrow$ fused depth map $\rightarrow$ platform-coordinate elevation field $\rightarrow$ four foot-region elevations $\rightarrow$ common-mode removal and travel scaling. A source-derived pipeline diagram should be inserted after this paragraph, showing these six stages and the four-leg output vector. A generative image is not suitable as evidence for this calibrated geometric process.

\newpage

\subsection{Task 5: IMU-Based Automatic Leveling}
\label{task:imu-leveling}

\subsubsection{Attitude Measurement and Arming}

Task~5 implemented the inertial feedback path used after touchdown to reduce residual platform roll and pitch. The BNO085 operates in UART-RVC mode and reports attitude data to the ESP32-P4. Before control, the software removes the installation zero and applies the validated orthogonal transformation from the IMU frame to the platform frame. This ensures that the controller responds to physical platform roll and pitch rather than to an arbitrary sensor-frame rotation.

IMU leveling is mutually exclusive with the terrain-elevation mode. Selecting a mode first sends STOP, clears any previous target vector, and requires a new explicit ARM operation. At ARM, the Mega verifies that all four VL53 sensors are fresh and within the $50$--$400~\mathrm{mm}$ valid range, captures the current readings as a four-leg baseline, and initializes all relative targets to zero. Thus every IMU correction is referenced to a known, measured landing posture.

\subsubsection{Differential PID Controller}

The controller aims to achieve
\[
|\phi|<1.0^\circ,
\qquad
|\theta|<1.0^\circ,
\]
where $\phi$ and $\theta$ are platform roll and pitch. Outside $5^\circ$ from level, proportional control provides rapid approach. Inside this region, reduced-gain PID control improves convergence while limiting oscillation. The implemented inner-loop gains are $K_P=1.0$, $K_I=0.5$, and $K_D=1.0$, with integral limiting and derivative filtering. The roll and pitch corrections are each bounded to $\pm50~\mathrm{mm}$ before conversion to actuator commands.

For the $200~\mathrm{mm}\times200~\mathrm{mm}$ four-corner platform, the differential mixer is
\[
\begin{aligned}
\Delta L_{\mathrm{FL}}&=\frac{-\Delta_R+\Delta_P}{\cos30^\circ}, &
\Delta L_{\mathrm{FR}}&=\frac{+\Delta_R+\Delta_P}{\cos30^\circ},\\
\Delta L_{\mathrm{RL}}&=\frac{-\Delta_R-\Delta_P}{\cos30^\circ}, &
\Delta L_{\mathrm{RR}}&=\frac{+\Delta_R-\Delta_P}{\cos30^\circ}.
\end{aligned}
\]
A roll error therefore produces opposite corrections on the left and right sides, while a pitch error produces opposite corrections on the front and rear sides. The four terms sum to zero, changing support-plane orientation without arbitrary collective heave. The command generator rate-limits the target change to $5~\mathrm{mm/s}$ and limits transmission to $10~\mathrm{Hz}$.

\subsubsection{Mega Feedback Loop and Safety}

The ESP32-P4 forwards FL--FR--RL--RR relative targets over USB Host--CH340 to the Arduino Mega, which maps them to its verified physical order A4--A3--A1--A2. The Mega closes the final actuator loop with the four VL53 sensors and stops a leg when its relative position error is within $1~\mathrm{mm}$. A $120~\mathrm{ms}$ break-before-make interval is enforced before direction reversal.

Safety remains local to the Mega. A heartbeat is required at least every $2~\mathrm{s}$; stale feedback, invalid or out-of-range VL53 readings, malformed commands, or heartbeat loss immediately disable all motor outputs and latch a fault. STOP returns the system to the disarmed all-output-low state, while ESTOP remains latched until reset. Therefore, an interrupted Wi-Fi link, frozen PC interface, or stale IMU stream cannot leave a landing leg energized without local position feedback.

\subsubsection{Task Outcome}

Task~5 produced the closed-loop chain BNO085 attitude $\rightarrow$ installation-frame transformation $\rightarrow$ bounded PID controller $\rightarrow$ zero-sum four-leg delta vector $\rightarrow$ Mega VL53 feedback. It complements Task~4: vision predicts a terrain-compensating landing configuration, while the IMU loop removes remaining measured roll and pitch after touchdown. A source-derived control-block diagram should be inserted after this paragraph, showing the BNO085, coordinate transformation, PID controller, differential mixer, P4--Mega link, VL53 feedback, and STOP/ESTOP safety loop.

\newpage

\subsection{Task 6: Simulated Terrain Design and Fabrication}

\newpage

\subsection{Task 7: System Integration and Validation}

\newpage

\section{Discussion}

\newpage

\section{Conclusions}
\label{sec:conclusions}

The objective of this project was to develop a self-stabilizing landing platform capable of reducing the tilt caused by uneven Martian terrain. To achieve this objective, the group designed and manufactured a four-leg aluminum-frame platform with independently adjustable linear actuators. The system combined terrain imaging, attitude sensing, actuator-position measurement, data processing, motor control, and closed-loop correction. After touchdown, the platform measured its inclination, calculated the required adjustment of each leg, and repeatedly corrected its attitude until the remaining tilt was reduced.

The completed prototype successfully met all four quantitative design objectives. Physical testing produced an average final tilt angle of \(2.61^\circ\), below the required limit of \(5.0^\circ\). The measured descent speed was \(5.2~\mathrm{cm/s}\), which was close to the target of approximately \(5~\mathrm{cm/s}\). The platform supported a payload of at least \(16~\mathrm{kg}\), exceeding the required \(15~\mathrm{kg}\), and completed 19 of 20 trials successfully, corresponding to a \(95\%\) success rate. The prototype was also completed at a total cost of \(958.1~\mathrm{RMB}\), which remained within the planned \(1000~\mathrm{RMB}\) budget.

The main contribution of the design is the integration of active post-touchdown leveling with independent leg control. Existing passive landing structures can absorb impact, while hazard-detection systems can help avoid dangerous regions before landing. In contrast, the proposed platform continues to respond after ground contact by measuring its actual attitude and correcting unequal landing-leg heights through feedback control. The project demonstrated that commercially available sensors, controllers, and actuators can be integrated into a relatively low-cost system capable of adapting to different uneven surfaces.

Several important lessons were learned during the project. Mechanical construction, sensor calibration, circuit connection, programming, and control testing must be treated as parts of one complete system rather than as separate tasks. Full-system integration should begin early because actuator inconsistency, sensor errors, structural misalignment, and communication problems may only appear when all components operate together. Although the prototype verified the feasibility of the design, future work should include Mars-like terrain testing, improved fault tolerance, greater payload capacity, and faster control convergence.

The broader significance of this project is its potential to improve the reliability of planetary exploration missions. A more level landing platform can provide better operating conditions for communication systems, solar panels, scientific instruments, and rover deployment. By reducing the risk of mission failure and protecting expensive onboard equipment, active self-leveling technology may improve scientific return while reducing the financial and resource losses associated with unsuccessful landings.

\newpage

\section{Schedule}

\newpage

\section{Bill of materials}

%==============================
% Bill of Materials
%==============================

\begin{center}
\renewcommand{\arraystretch}{1.18}

\begin{longtable}{
@{}
p{0.08\textwidth}
>{\centering\arraybackslash}p{0.34\textwidth}
>{\centering\arraybackslash}p{0.16\textwidth}
>{\centering\arraybackslash}p{0.16\textwidth}
>{\centering\arraybackslash}p{0.12\textwidth}
@{}
}

\caption{\quad \textbf{Bill of materials (BOM)}}
\label{tab:bill_of_materials}\\

\hline
\hline

Quantity & Part Description & Purchased From* & Part Number & Cost (RMB)\\

\midrule
\endfirsthead

\hline
\hline

Quantity & Part Description & Purchased From* & Part Number & Cost (RMB)\\

\midrule
\endhead

1 & ESP32-P4-NANO development board with WiFi 6 Kit A & Taobao [1] & ESP32-P4-NANO & 165.00 \\

1 & Four-channel motor driver module & Taobao [2] & L298N & 35.62 \\

4 & Mini linear actuator, 12 V, 200 mm stroke, 20 mm/s & Taobao [3] & 12V-200mm & 400.00 \\

1 & European standard 2020L aluminum extrusion frame & Taobao [4] & 2020L & 216.54 \\

1 & I2C multiplexer module & Taobao [5] & TCA9548A & 20.00 \\

4 & Laser distance measurement module & Taobao [6] & VL53L0X & 100.00 \\

1 & 9-axis IMU sensor & Taobao & BNO085 & 84.00 \\

1 & Camera module & Taobao & OV5647 & 114.60 \\

\hline
\hline

&
&
&
\textbf{Total =}
&
\textbf{1170.96}

\end{longtable}

\vspace{0.15cm}

\noindent
\textbf{*Purchase links:}

\begin{enumerate}

\item
\url{https://e.tb.cn/h.RvltKvSMPLN7kzW?tk=O5Ybg97dI3w}

\item
\url{https://e.tb.cn/h.RueoXSIDdBIatIH?tk=5xNbg97X4Lz}

\item
\url{https://e.tb.cn/h.RFdis51r2zfegjp?tk=YKlhg97cRSt}

\item
\url{https://e.tb.cn/h.RuGLJzAbn9LrmKU?tk=LAn9gkFmqG3}

\item
\url{https://e.tb.cn/h.8WyMNK8ZtYsXuU9?tk=EksMgE9D4Nv}

\item
\url{https://e.tb.cn/h.83wSaOYP19eBEZn?tk=BfL8gE9x70m}

\end{enumerate}

\renewcommand{\arraystretch}{1.2}

\end{center}

\newpage

\section{Key Personnel}

\newpage

\bibliography{reference}

\newpage

\section{Appendix}

\subsection{Winch Motor Control Code}

The following Arduino program was developed to control the four winch motors used in the descent mechanism of the landing platform. The program controls four DC motors through L298N motor drivers and provides bidirectional rotation, start/stop control, and direction switching through user input buttons. Individual PWM values are assigned to each motor to compensate for speed variations and achieve synchronized cable deployment and retrieval during the descent process.

\begin{lstlisting}[style=appendixcode,language=C++]
// ==================== Motor Pins ====================
// Avoid using UNO D0/D1 because they are reserved for Serial RX/TX.
// Original M1_IN1=0 and M1_IN2=1. Changed to A2 and A3.

const int M1_IN1=A2,M1_IN2=A3,M2_IN1=2,M2_IN2=8; // First L298N

const int M3_IN1=4,M3_IN2=5,M4_IN1=6,M4_IN2=7; // Second L298N

const int M1_EN=9,M2_EN=10,M3_EN=11,M4_EN=3; // ENA / ENB pins must be connected to PWM pins

// ==================== Button Pins ====================

// Yellow button: Start / Stop Blue button: Forward / Reverse

const int YELLOW_BUTTON=A0,BLUE_BUTTON=A1;

// Button module outputs HIGH when pressed const int PRESSED_LEVEL=HIGH;

// ==================== Speed Settings ====================

// Motor mapping:
// M1 = First L298N OUT1/OUT2 M2 = First L298N OUT3/OUT4 M3 = Second L298N OUT1/OUT2 M4 = Second L298N OUT3/OUT4

// Forward startup PWM
const int FORWARD_START_PWM[4]={180,180,180,180};

// Forward running PWM
// Adjusted individually to compensate for motor speed differences.
int FORWARD_RUN_PWM[4]={33,33,36,41};

// Reverse startup PWM
const int REVERSE_START_PWM[4]={220,220,220,220};

// Reverse running PWM
// Higher values are required to overcome gravity during cable retrieval.
int REVERSE_RUN_PWM[4]={120,120,100,120};

// Startup high PWM duration
const unsigned long START_TIME=300;

// Delay before changing motor direction
const unsigned long DIRECTION_CHANGE_DELAY=500;

// ==================== Current State ====================

bool isRunning=false;
bool isForward=true;

int lastYellowState=LOW,lastBlueState=LOW;

unsigned long lastYellowTime=0,lastBlueTime=0;

const unsigned long debounceDelay=50;

// ==================== Initialization ====================

void setup(){
  pinMode(M1_IN1,OUTPUT); pinMode(M1_IN2,OUTPUT);
  pinMode(M2_IN1,OUTPUT); pinMode(M2_IN2,OUTPUT);
  pinMode(M3_IN1,OUTPUT); pinMode(M3_IN2,OUTPUT);
  pinMode(M4_IN1,OUTPUT); pinMode(M4_IN2,OUTPUT);

  pinMode(M1_EN,OUTPUT); pinMode(M2_EN,OUTPUT);
  pinMode(M3_EN,OUTPUT); pinMode(M4_EN,OUTPUT);

  pinMode(YELLOW_BUTTON,INPUT); pinMode(BLUE_BUTTON,INPUT);

  brakeMotors();
}

// ==================== Main Loop ====================

void loop(){
  handleYellowButton();
  handleBlueButton();
}

// ==================== Yellow Button ====================// Controls start / stop.

void handleYellowButton(){
  int currentState=digitalRead(YELLOW_BUTTON);

  if(currentState==PRESSED_LEVEL &&
     lastYellowState!=PRESSED_LEVEL &&
     millis()-lastYellowTime>debounceDelay){

    isRunning=!isRunning;

    if(isRunning){
      startMotors();
    }
    else{
      brakeMotors();
    }

    lastYellowTime=millis();
  }
  lastYellowState=currentState;
}

// ==================== Blue Button ==================== // Controls forward / reverse direction.

void handleBlueButton(){
  int currentState=digitalRead(BLUE_BUTTON);

  if(currentState==PRESSED_LEVEL &&
     lastBlueState!=PRESSED_LEVEL &&
     millis()-lastBlueTime>debounceDelay){

    if(isRunning){ // Brake before changing direction.
      brakeMotors();
      delay(DIRECTION_CHANGE_DELAY);
    }
    isForward=!isForward;

    if(isRunning){
      startMotors();
    }

    lastBlueTime=millis();
  }

  lastBlueState=currentState;
}

// ==================== Direction Control ====================

void applyDirection(){
  if(isForward){
    setDirectionForward();
  }
  else{
    setDirectionReverse();
  }
}

// ==================== Forward Direction ====================

void setDirectionForward(){

  digitalWrite(M1_IN1,HIGH); digitalWrite(M1_IN2,LOW);
  digitalWrite(M2_IN1,HIGH); digitalWrite(M2_IN2,LOW);
  digitalWrite(M3_IN1,HIGH); digitalWrite(M3_IN2,LOW);
  digitalWrite(M4_IN1,HIGH); digitalWrite(M4_IN2,LOW);
}

// ==================== Reverse Direction ====================

void setDirectionReverse(){

  digitalWrite(M1_IN1,LOW); digitalWrite(M1_IN2,HIGH);
  digitalWrite(M2_IN1,LOW); digitalWrite(M2_IN2,HIGH);
  digitalWrite(M3_IN1,LOW); digitalWrite(M3_IN2,HIGH);
  digitalWrite(M4_IN1,LOW); digitalWrite(M4_IN2,HIGH);
}

// ==================== Motor Start ====================

void startMotors(){

  applyDirection();

  if(isForward){

    setAllMotorPWM(FORWARD_START_PWM);
    delay(START_TIME);
    setAllMotorPWM(FORWARD_RUN_PWM);

  }
  else{

    setAllMotorPWM(REVERSE_START_PWM);
    delay(START_TIME);
    setAllMotorPWM(REVERSE_RUN_PWM);

  }
}

// ==================== Brake Stop ==================== // Keeps EN pins HIGH and sets IN1/IN2 to the same level.
// L298N enters short brake mode.

void brakeMotors(){

  digitalWrite(M1_IN1,LOW); digitalWrite(M1_IN2,LOW);
  digitalWrite(M2_IN1,LOW); digitalWrite(M2_IN2,LOW);
  digitalWrite(M3_IN1,LOW); digitalWrite(M3_IN2,LOW);
  digitalWrite(M4_IN1,LOW);digitalWrite(M4_IN2,LOW);

  analogWrite(M1_EN,255); analogWrite(M2_EN,255);
  analogWrite(M3_EN,255); analogWrite(M4_EN,255);
}

// ==================== Coast Stop ==================== // Not recommended when motors are holding a suspended platform.

void coastMotors(){

  analogWrite(M1_EN,0); analogWrite(M2_EN,0);
  analogWrite(M3_EN,0); analogWrite(M4_EN,0);

}

// ==================== Set Motor PWM ====================

void setAllMotorPWM(const int pwmValues[4]){

  analogWrite(M1_EN,constrain(pwmValues[0],0,255)); analogWrite(M2_EN,constrain(pwmValues[1],0,255));
  analogWrite(M3_EN,constrain(pwmValues[2],0,255)); analogWrite(M4_EN,constrain(pwmValues[3],0,255));

}

\end{lstlisting}

\end{document}

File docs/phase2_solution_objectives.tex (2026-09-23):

% Paste-ready content for the Phase 2 Report Template.
% Requires: amsmath, amssymb, enumitem.

\section{Solution: Terrain-Adaptive Four-Legged Mars Lander}

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

The proposed solution is a terrain-adaptive Mars landing platform intended to reduce post-touchdown tilt when the four landing feet contact terrain of unequal elevation. The platform is approximately $200\,\mathrm{mm}\times200\,\mathrm{mm}$, with one independently driven linear actuator at each corner. A rigid landing configuration transfers local terrain height differences directly into platform roll and pitch; consequently, it can degrade payload stability, camera pointing, and the available actuator travel margin. The proposed system instead treats the four leg positions as independently regulated variables and uses their coordinated motion to alter the support plane formed by the landing feet.

The physical actuators are designated FL, FR, RL, and RR. Their mapping to the Mega controller is fixed as
\[
\mathrm{FL}\rightarrow A4,\qquad
\mathrm{FR}\rightarrow A3,\qquad
\mathrm{RL}\rightarrow A1,\qquad
\mathrm{RR}\rightarrow A2.
\]
This mapping is essential because the geometric solver uses the order FL--FR--RL--RR whereas the electrical controller uses A1--A4. Each actuator has a dedicated VL53L1X time-of-flight sensor. The four equal-address sensors are isolated through a TCA9548A I$^2$C multiplexer, enabling the Mega to acquire independent position feedback for every leg. The verified direction convention is
\[
\text{EXTEND}\Rightarrow d_i\ \text{increases},
\qquad
\text{RETRACT}\Rightarrow d_i\ \text{decreases},
\]
where $d_i$ is the local VL53 coordinate of actuator $i$.

For every requested target $d_{i,\mathrm{target}}$, the Mega calculates the local position error
\[
e_i=d_{i,\mathrm{target}}-d_{i,\mathrm{measured}}.
\]
A positive error commands extension and a negative error commands retraction. The actuator output is disabled after the target is reached within the specified tolerance. This local feedback loop is executed on the Mega rather than on the PC, so a delayed Wi-Fi packet, a frozen camera frame, or a Windows application failure cannot remove the fundamental position-feedback and stop functions. Direction reversal includes a $120\,\mathrm{ms}$ break-before-make interval, preventing opposing motor-drive states from being applied simultaneously.

\subsection*{Stage-1 Elevation-Map Landing-Leg Control}

Stage~1 implements the completed terrain-adaptive landing controller. The OV5647 fisheye camera provides an elevation map of the landing area, while the calibrated camera geometry projects the four predicted foot-contact regions into that map. The controller samples a robust local elevation $h_i$ for each foot region $i\in\{\mathrm{FL},\mathrm{FR},\mathrm{RL},\mathrm{RR}\}$. Invalid pixels, regions outside the valid depth field, and inconsistent local estimates are rejected before target generation. The HC-SR04 provides the global millimetre scale anchor for the reconstructed elevation field; it is not used as an independent per-leg height sensor.

The controller removes the common elevation component so that it commands only support-plane compensation rather than an arbitrary collective translation. With
\[
\bar h=\frac{1}{4}\sum_{j=1}^{4}h_j,
\qquad
\Delta h_i=h_i-\bar h,
\qquad
\sum_{i=1}^{4}\Delta h_i=0,
\]
the required leg-length correction is generated as
\[
L_{i,\mathrm{target}}=L_{i,0}+k_h\Delta h_i,
\]
where $L_{i,0}$ is the established landing reference length and $k_h$ is the calibrated sign and scale factor relating terrain elevation to actuator length. Thus, a relative terrain-height change modifies the landing-leg configuration while preserving the mean commanded length. The Console and P4 remap the geometric order FL--FR--RL--RR to the fixed Mega order A4--A3--A1--A2 before sending the four targets to the common Mega position-control routine.

Each candidate correction is constrained to the approved differential travel envelope $|\Delta L_i|\leq100\,\mathrm{mm}$. If a candidate would cross a leg travel boundary, all four differential corrections are reduced by one common scale factor rather than clipping individual legs. This preserves the intended support-plane orientation and the zero-sum condition. The Mega then closes the four local VL53L1X feedback loops independently; it stops each output on target, stale feedback, invalid feedback, timeout, STOP, or ESTOP. Consequently, the elevation map selects the coordinated target geometry, while the hardware-proven Mega loop remains responsible for final actuator positioning and non-motion safety.

The Stage-1 result is a complete path from camera-derived terrain elevations to bounded four-leg target lengths. It compensates the relative elevation differences across the four foot regions and therefore reduces predicted post-touchdown roll and pitch without treating the absolute terrain range as an individual leg command.

\subsection*{IMU Attitude-Control Solution}

The second control owner is the IMU mode. It is mutually exclusive with Stage-1 elevation-map control: switching modes first issues STOP to the active owner, clears pending targets, and requires a new explicit ARM action. The BNO085 provides platform attitude. Its installation-frame transformation converts the sensor reading into platform roll and pitch, which are then used to generate coordinated differential leg corrections. The target condition is approximately
\[
|\phi_{\mathrm{platform}}|\leq1^\circ,
\qquad
|\theta_{\mathrm{platform}}|\leq1^\circ.
\]

IMU control changes opposing corners in opposite directions where appropriate, producing a change in support-plane orientation rather than an arbitrary common vertical displacement. The existing IMU pathway retains its validated outer attitude correction, inner position regulation, bounded target update rate, and Mega-side local safety checks. It is therefore an automatic leveling mode based on measured inertial state, complementary to the completed Stage-1 terrain-elevation controller.

\subsection*{Safety and Communication Solution}

The lander uses a layered authority model. The PC Console provides user interaction, status visualization, and high-level mode requests. The ESP32-P4 handles Wi-Fi, the camera and IMU interfaces, USB Host communication, and a single serialized command path to the Mega CH340 interface. The Mega remains the actuator safety authority. It implements the states \texttt{LOCKED}, \texttt{STAGE1\_ELEVATION}, \texttt{IMU\_ACTIVE}, \texttt{FAULT}, and \texttt{ESTOP}.

In \texttt{LOCKED}, \texttt{FAULT}, and \texttt{ESTOP}, all motor enable and direction outputs are low. Host-owned sessions require a heartbeat; if no valid heartbeat arrives within two seconds, the Mega stops the outputs. Each VL53 reading must be valid and newer than the sensor freshness threshold. The controller also rejects targets above the $400\,\mathrm{mm}$ upper limit. STOP and ESTOP bypass normal motion authorization. Consequently, the proposed lander does not rely on correct PC software, continuous Wi-Fi, or valid computer vision to preserve a safe non-motion state.

\section{Objectives}

\textbf{Objective 1: Develop and validate the four-leg local position-feedback subsystem.}

This objective is to implement deterministic position feedback for all four actuators using the Mega, the TCA9548A multiplexer, and four VL53L1X sensors. The subsystem must maintain the verified FL/FR/RL/RR-to-A4/A3/A1/A2 mapping, use the measured direction convention, perform independent feedback updates, and disable outputs when sensor data are invalid or stale. Achieving this objective provides the measurable foundation required for all subsequent Stage-1 elevation-map and IMU-based landing operations; without local position feedback, the system cannot verify whether a requested landing configuration has been reached.

\textbf{Objective 2: Complete and validate Stage-1 elevation-map-based four-leg control.}

This objective is to derive a robust relative terrain elevation for each of the four projected foot-contact regions from the calibrated camera elevation map, use the HC-SR04 only to anchor the map scale, remove the common elevation component, and generate the bounded zero-sum four-leg target vector. The mode must reject invalid foot regions, preserve $\sum_i\Delta L_i=0$, apply common-factor scaling at travel limits, and remain explicitly armed and mutually exclusive with the IMU owner. The benefit is a direct and auditable terrain-to-actuator pathway that compensates uneven touchdown geometry without turning absolute range or visually invalid depth into an unsafe individual-leg command.

\textbf{Objective 3: Integrate the elevation-map target vector with the Mega position controller.}

This objective is to map the geometric target order FL, FR, RL, and RR to Mega order A4, A3, A1, and A2, then send the four absolute targets through the P4 to the common Mega position-control pathway. The system must reject malformed, out-of-range, stale, or inconsistent requests and display actual leg feedback and controller state. This objective provides a repeatable, hardware-protected final stage for terrain adaptation while avoiding duplicate motor-control implementations.

\textbf{Objective 4: Maintain a mutually exclusive IMU-based attitude-correction mode.}

This objective is to preserve and verify the BNO085-based attitude-control pathway as a distinct owner that can reduce platform roll and pitch after touchdown. The mode must use the validated IMU installation transformation, bounded correction behavior, the existing PID structure, and the same Mega-side safety protections as Stage-1 elevation-map control. The benefit is an automatic post-touchdown leveling capability that can compensate for residual tilt, actuator tolerance, and small unmodeled terrain variations after a stable support configuration has been established.

\textbf{Objective 5: Maintain the completed elevation-map terrain-adaptation pathway.}

This objective is to maintain the calibrated fisheye model, camera-pose transformation, SR04 scale anchor, and measured plane/step validation that support Stage-1 elevation-map control. The terrain controller uses only relative four-foot elevation differences,
\[
\delta_i=L_i-\frac{1}{4}\sum_{j=1}^{4}L_j,
\qquad \sum_i\delta_i=0,
\]
with common-factor scaling near travel boundaries. The benefit is a documented autonomous terrain-adaptation capability that converts calibrated relative elevations into physically bounded landing-leg compensation while retaining the Mega-side safety authority.

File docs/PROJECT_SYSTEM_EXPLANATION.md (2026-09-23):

# Mars Lander Project — System Architecture and Engineering Explanation

## 1. Mission Context

The project develops a four-legged landing platform for a Mars-exploration scenario in which a lander must settle on locally uneven terrain. A rigid landing platform can transfer terrain height differences directly into body roll and pitch. Large tilt can compromise camera pointing, payload stability, solar-array orientation, and the useful range of the landing legs. The engineering objective is therefore to estimate or measure the relative elevation of four support regions and independently regulate the four landing legs so that the platform reaches a controlled attitude.

The current prototype separates this long-term objective into a safe operational layer and a research layer. The operational layer provides deterministic leg control through a source-faithful physical Remote and a validated inertial mode. The research layer develops camera calibration, depth reconstruction, ultrasonic depth scaling, and foot-region terrain analysis. This separation prevents an unvalidated AI or vision estimate from commanding hardware.

## 2. Architecture Overview

```text
                       Windows PC
       ┌─────────────────────────────────────┐
       │ Console: mode, Remote targets,       │
       │ status, video/IMU display, CV study  │
       └──────────────────┬──────────────────┘
                          │ Wi-Fi / HTTP / TCP
                          ▼
                     ESP32-P4 Gateway
       ┌─────────────────────────────────────┐
       │ OV5647 camera / BNO085 / Wi-Fi      │
       │ USB Host / CH340 / Mega protocol    │
       │ HTTP /board, /health, /cmd          │
       └──────────────────┬──────────────────┘
                          │ USB Host to CH340
                          ▼
                    Arduino Mega 2560
       ┌─────────────────────────────────────┐
       │ PS2 Remote / four VL53L1X sensors   │
       │ TCA9548A / motor outputs / SR04     │
       │ local feedback, timeout, STOP/ESTOP │
       └───────────┬───────────┬─────────────┘
                   ▼           ▼
          Four linear actuators   Four corner feet
```

The Mega is the safety-critical actuator authority. The PC and P4 can request a command, but they cannot replace the Mega's local sensor feedback, range checks, staleness checks, heartbeat timeout, or output-disable behavior. This allocation is deliberate: wireless transport, computer vision, or the Windows user interface can fail without removing local actuator protection.

## 3. Mechanical and Sensor Architecture

The lander platform is approximately \(200\times200\) mm, with an independently driven actuator at each corner. Each actuator has a VL53L1X time-of-flight sensor measuring the relevant local position coordinate. The four equal-address sensors are selected through a TCA9548A I\textsuperscript{2}C multiplexer.

The canonical physical mapping is:

```text
A1 = RL, rear-left
A2 = RR, rear-right
A3 = FR, front-right
A4 = FL, front-left

UI / solver order: FL, FR, RL, RR
```

The actuator direction convention is defined in the actual feedback coordinate:

```text
EXTEND  increases the associated VL53 reading.
RETRACT decreases the associated VL53 reading.
```

The camera is centered and points downward. Its optical center is approximately 50 mm below the upper-joint plane. The BNO085 provides orientation information. The HC-SR04 is physically connected to the Mega and is used only as a possible absolute scale anchor for visual depth research, not as a direct command variable for leg height.

## 4. Stage-1 Control Design

### 4.1 Why Stage 1 does not use automatic CV actuation

A visual depth map may be temporally stable while still being geometrically wrong for a particular lens, lighting condition, material, or terrain texture. It can also fail when one foot region is occluded or outside the visible field. Therefore, the project explicitly prevents automatic camera/depth output from entering the actuator command channel during Stage 1.

The Console label ``CV Control'' is retained for the user interface, but its Stage-1 implementation is a Remote owner. This mode enables a physical PS2 Remote, the original preset-selection behavior, and controlled direct entry of four absolute VL53 targets. It does not mean that camera output can move the legs.

### 4.2 Faithful Remote behavior

The source Remote program was hash-locked and used as the behavior baseline. It preserves the PS2 pin assignment, manual mappings, START-button transition between manual and preset selection, 16 preset vectors, preset order, connection retry behavior, and completion logic. The Remote is not merely simulated by the Console.

Manual commands use held buttons: releasing a button stops the corresponding leg. Preset mode uses 16 pre-defined four-leg target vectors. Target completion requires two independent in-tolerance sensor confirmations; the action times out after 30 s. Three consecutive Remote read failures declare a disconnection and stop the outputs.

The Console provides an additional Remote input surface. It accepts FL/FR/RL/RR targets in the actual VL53 coordinate, maps them to A4/A3/A1/A2, and sends a `SET_REMOTE` request through the P4. Console target motion temporarily pauses PS2 command processing. On completion or cancellation, the Remote session returns to PS2 operation.

### 4.3 IMU mode

IMU mode is a distinct owner. It uses BNO085 attitude feedback and a pre-validated coordinate transformation to reduce measured roll and pitch. It cannot be active together with Remote mode. A mode change stops the current owner before the next owner may be armed.

The IMU loop converts attitude error into coordinated differential leg adjustments. It seeks to change the support-plane orientation rather than apply an arbitrary common vertical motion. Existing PID and rate-limit behavior remain in the IMU pathway; Stage-1 Remote work must not replace or retune this controller without separate commissioning evidence.

## 5. Local Safety Model

The Mega implements the following state model:

```text
LOCKED
  all motor outputs low; movement blocked.

REMOTE_MANUAL / REMOTE_PRESET
  physical Remote enabled after explicit ARM REMOTE.

ARMED / ACTIVE
  IMU owner enabled after explicit ARM IMU.

FAULT / ESTOP
  outputs low; normal motion blocked until correct recovery action.
```

Key local protections are:

- four valid, fresh VL53 position readings;
- active coordinate upper bound of 400 mm and current lower bound of 0 mm;
- 1200 ms sensor freshness timeout;
- 2 s heartbeat timeout for host-owned sessions;
- explicit STOP and latched ESTOP;
- all outputs low in LOCKED, FAULT, and ESTOP;
- 120 ms break-before-make for direction reversal;
- local target validation before motor output;
- full-group rejection of invalid targets.

The lower bound was changed from 50 mm to 0 mm after a physical channel reported a valid reading below 50 mm. This was a targeted correction to an over-restrictive range rule, not removal of the sensor-validity, stale-data, upper-travel, heartbeat, or emergency-stop protections.

## 6. P4 Gateway and PC Console

The ESP32-P4 is the communication gateway. It captures camera images, receives BNO085 data, serves the network interfaces, manages the USB Host connection to the Mega's CH340 interface, and serializes all commands sent to the Mega.

The P4 provides a strict identity endpoint:

```text
GET /board  →  board=ESP32-P4 plus current DHCP address
```

The Windows Console must verify this identity rather than assume a historical IP address. `/health` reports the current Mega state, four-leg feedback, Remote state, PS2 connection state, and serial receive counters. These counters are important because a stale status object is not proof that the Mega application is currently running.

The P4 has two corresponding Remote command requests:

```text
remote_arm
remote_set_absolute(seq, FL, FR, RL, RR)
```

The P4 sends these through the same serialized CH340 command path used by the IMU commands. There is no parallel write path that could corrupt command lines or sequence ordering.

## 7. Vision and Depth Research Path

The project has completed fisheye intrinsic calibration using 36 views. The accepted calibration has RMS reprojection error of approximately 0.717 pixels. An external camera-to-board pose collection also produced a mean reprojection error of approximately 0.345 pixels and a camera-to-plane distance of approximately 354.73 mm. However, the front/back orientation ambiguity is not yet resolved, so the current external pose is not a control input.

The intended depth pipeline is:

```text
camera image
→ fisheye-aware geometry
→ model relative depth
→ stable local terrain estimate
→ SR04 scale anchor when its independent-sample window is stable
→ four foot-region elevation estimates
→ zero-common-mode relative leg correction proposal
```

The relative leg correction must satisfy

\[
\delta_i=L_i-\frac{1}{4}\sum_{j=1}^{4}L_j,
\qquad \sum_i\delta_i=0.
\]

This rejects the physically unhelpful case in which all legs are moved by the same amount merely because the entire estimated terrain map has a common scale or offset error. Each correction is bounded to \(\pm100\) mm relative to the mean. If a boundary is reached, the whole differential vector must be scaled by one common factor; independently clipping individual legs would distort the desired platform slope.

Before Stage-2 actuation can be considered, the project still needs flat-plane tests, measured 10/20/30/50 mm step tests, front/back pose disambiguation, repeated scale-anchor validation, and staged low-amplitude hardware tests.

## 8. Deployment and Verification Strategy

Firmware is built with the real Windows toolchains and flashed through the P4 debug interface on COM5. Mega application updates are performed through a controlled temporary P4 bridge. The update procedure verifies the ATmega2560 signature, writes only the application area, and reads every written flash page back for comparison. The P4 production image is restored after the bridge operation.

The safe verification sequence is always:

```text
1. Verify P4 identity.
2. Verify increasing Mega RX counters.
3. Verify LOCKED, fault=none, all four VL53 valid.
4. Verify target=0 and applied=0.
5. Arm only one owner explicitly.
6. Begin with no-motion and very small displacement tests.
7. STOP and re-check LOCKED after each test.
```

This architecture allows the project to make measurable progress on terrain sensing and control while maintaining a clear boundary between research output and real actuator authority.

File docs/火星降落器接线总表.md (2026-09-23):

# 火星降落器接线总表（持续维护）

> **用途**：本文件是火星降落器实际电气接线的唯一汇总入口。每次改变实体接线、端口、GPIO 分配、供电或固件所依赖的连接时，必须同步更新本文件，并在“变更记录”中增加一行。
>
> **安全原则**：所有未在“已确认”列明确标注的项目，均不得当作已完成实体接线。推杆运动路径目前保持安全锁定，不能因为表中存在历史引脚方案而解锁。

## 1. 文档状态

| 项目 | 内容 |
|---|---|
| 文档版本 | v1.0 |
| 建立时间 | 2026-08-07 23:04 CST |
| 当前主控 | ESP32-P4 Function EV Board v1.3（Waveshare ESP32-P4-NANO） |
| 当前数据通路 | OV5647 相机 + BNO085 UART-RVC + P4 USB Host→CH340→Arduino Mega→HC-SR04；P4 通过 SDIO 接 ESP32-C6 提供 Wi-Fi |
| 本表依据 | 当前 `wifi_test` 固件源代码、`mega_lander_actuator_controller.ino`、`mega_sr04_bridge_diagnostic.ino` 与已经确认的项目接线结论 |
| 维护规则 | 先以实物、数据手册及串口日志为准；确认后再改本表及对应源码注释。代码中的历史/候选方案必须明确标注，不得覆盖已验证接线。 |

## 2. 系统连接概览

```text
OV5647 ── MIPI-CSI + SCCB/I²C + XCLK ──> ESP32-P4 ── SDIO(4-bit) ──> ESP32-C6 ── Wi-Fi ──> PC 控制台
                                               │
BNO085 ── UART-RVC（单向 TX→RX）───────────────┤
                                               │ USB-A（USB OTG Host）
                                               v
                             Arduino Mega 2560（USB-B / CH340）
                               └── HC-SR04（距离标尺校正；不用于单腿闭环）

Arduino Mega 2560 ── I²C ──> TCA9548A ── CH0..CH3 ──> 4×VL53L1X（推杆长度/行程传感器）
Arduino Mega 2560 ── 数字输出 ──> 4 路推杆驱动器 IN1 / IN2 / EN
```

## 3. 供电与共地

| 编号 | 连接 | 端点 A | 端点 B | 电压/要求 | 状态 | 说明 |
|---|---|---|---|---|---|---|
| PWR-01 | 主控供电 | ESP32-P4-NANO | 已安装电源系统 | 按开发板规定供电 | 待实物复核 | 本仓库未记录电源模块型号、输入端和保险保护信息；接入前必须补录。 |
| PWR-02 | 传感器供电 | BNO085 | 稳压 3.3 V 与 GND | **仅 3.3 V 逻辑/供电** | 待实物复核 | UART 信号接 P4 GPIO3；不可把 5 V UART 直接接入 P4。 |
| PWR-03 | 相机供电 | OV5647 | P4 MIPI-CSI 接口 | 由 CSI 接口/板载电源提供 | 已由相机链路使用 | 使用排线，不单独飞线供电。 |
| PWR-04 | 超声波供电 | HC-SR04 VCC/GND | Arduino Mega 5V/GND | 5 V | 已确认（诊断固件） | 仅由 Mega 采样。 |
| PWR-05 | 共地 | Mega / HC-SR04 / 推杆驱动与电源系统 | 系统公共地 | 必须共地 | 待实物复核 | 推杆驱动器与 Mega 控制信号必须共参考地；补录实际接地点和线径。 |
| PWR-06 | 推杆动力电源 | 4 路推杆驱动器 | 独立动力电源 | **待补录额定电压/电流/保险** | 待实物复核 | 不得由 Mega 或 P4 的 5V 引脚供给推杆动力。 |

## 4. ESP32-P4-NANO：相机 OV5647

| 编号 | 信号 | ESP32-P4 端 | OV5647/相机端 | 状态 | 代码依据/备注 |
|---|---|---|---|---|---|
| CAM-01 | MIPI CSI 数据 | P4 MIPI-CSI 2-lane 接口 | OV5647 MIPI-CSI 排线 | 已由相机链路使用 | `main/camera.c` 配置 2 条 CSI 数据 lane；排线方向、接口标识需在实物照片/装配图补录。 |
| CAM-02 | SCCB SDA | GPIO7 | 相机 SDA | 已确认（固件配置） | `CAM_I2C_SDA_PIN=7`。 |
| CAM-03 | SCCB SCL | GPIO8 | 相机 SCL | 已确认（固件配置） | `CAM_I2C_SCL_PIN=8`，100 kHz。 |
| CAM-04 | XCLK | GPIO40 | 相机 XCLK | 已确认（固件配置） | `CAM_XCLK_PIN=40`，24 MHz。 |
| CAM-05 | CSI LDO | P4 内部 LDO 通道 3 | CSI 电源域 | 已确认（固件配置） | 2.5 V；不是外部飞线。 |

## 5. ESP32-P4-NANO：BNO085 IMU（UART-RVC）

| 编号 | 信号 | BNO085 端 | ESP32-P4 端 | 状态 | 要求/备注 |
|---|---|---|---|---|---|
| IMU-01 | 模式选择 PS0 | PS0 | 3.3 V | 已确认（固件注释/已验证通路） | 与 PS1 组合设为 UART-RVC 模式。 |
| IMU-02 | 模式选择 PS1 | PS1 | GND | 已确认（固件注释/已验证通路） | 与 PS0 组合设为 UART-RVC 模式。 |
| IMU-03 | IMU 串行输出 | 标为 SDA/TX 的输出脚 | GPIO3（UART1 RX） | 已确认（固件配置） | 115200 baud，19-byte RVC 包，目标采样 100 Hz；当前只使用 IMU→P4 单向数据。 |
| IMU-04 | 供电 | VIN/3V3、GND | 3.3 V、GND | 待实物复核 | 需要确认所用 BNO085 小板具体丝印与 VIN 是否带稳压；P4 GPIO 绝不可承受 5V。 |
| IMU-05 | 其他串口线 | P4 TX/RTS/CTS | BNO085 | 未连接/未使用 | 当前固件无 TX、RTS、CTS；不要自行补接。 |

## 6. ESP32-P4-NANO：ESP32-C6 Wi-Fi 协处理器（SDIO）

| 编号 | 信号 | ESP32-P4 端 | ESP32-C6 端 | 状态 | 备注 |
|---|---|---|---|---|---|
| C6-01 | SDIO CLK | GPIO18 | C6 SDIO CLK | 已确认（`sdkconfig`） | 4-bit SDIO，20 MHz。 |
| C6-02 | SDIO CMD | GPIO19 | C6 SDIO CMD | 已确认（`sdkconfig`） | 3.3 V 逻辑。 |
| C6-03 | SDIO D0 | GPIO14 | C6 SDIO D0 | 已确认（`sdkconfig`） | **与旧 P4 推杆 RR PWM 方案冲突；GPIO14 禁止用于推杆。** |
| C6-04 | SDIO D1 | GPIO15 | C6 SDIO D1 | 已确认（`sdkconfig`） | 4-bit 总线。 |
| C6-05 | SDIO D2 | GPIO16 | C6 SDIO D2 | 已确认（`sdkconfig`） | 4-bit 总线。 |
| C6-06 | SDIO D3 | GPIO17 | C6 SDIO D3 | 已确认（`sdkconfig`） | 4-bit 总线。 |
| C6-07 | C6 复位 | GPIO54 | C6 RESET | 已确认（`sdkconfig`） | Active-high reset 配置；接线/复位极性如与实物模块不一致必须立即停用并核对。 |
| C6-08 | 供电与地 | 3.3 V/GND | C6 3.3 V/GND | 待实物复核 | 需要补录模块型号、供电来源、上拉电阻与线束长度。 |

## 7. ESP32-P4 USB Host ↔ Arduino Mega 2560

| 编号 | 信号/接口 | ESP32-P4 端 | Arduino Mega 端 | 状态 | 备注 |
|---|---|---|---|---|---|
| USB-01 | USB 数据与供电 | P4 板载 USB-A（USB OTG 2.0 HS Host） | Mega USB-B（CH340） | 已确认 | P4 的 USB-A 是 Host 数据口；当前固件通过 CH340 VCP 枚举 Mega，串口 115200。 |
| USB-02 | 串口协议 | USB Host CH340 VCP | Mega `Serial` | 已确认（固件配置） | P4 轮询 Mega 的 SR04 状态；当前主固件的 Mega 运动命令编译期安全锁定。 |
| USB-03 | 外部共地 | USB 屏蔽/地 | Mega USB 地 | 已由 USB 连接 | 推杆动力地仍应另行按 PWR-05 确认共地。 |

## 8. Arduino Mega 2560：HC-SR04（当前使用的诊断接线）

| 编号 | 信号 | HC-SR04 端 | Mega 端 | 状态 | 备注 |
|---|---|---|---|---|---|
| SR04-01 | 触发 | TRIG | D51 | 已确认（`mega_sr04_bridge_diagnostic.ino`） | 10 µs 高电平触发。 |
| SR04-02 | 回波 | ECHO | D50 | 已确认（`mega_sr04_bridge_diagnostic.ino`） | Mega 为 5 V 逻辑，直接读取允许；**不要接到 P4 GPIO**。 |
| SR04-03 | 电源 | VCC | 5V | 已确认（诊断固件注释） | 传感器额定 5 V。 |
| SR04-04 | 地 | GND | GND | 已确认（诊断固件注释） | 与 Mega 地相连。 |
| SR04-05 | 数据职责 | 测距结果 | Mega Serial→P4 USB | 已确认 | 仅用于整张深度图毫米尺度校正，不作为四腿独立闭环高度传感器。 |

### 历史冲突记录：HC-SR04 引脚

| 方案 | TRIG | ECHO | 状态 | 处理要求 |
|---|---:|---:|---|---|
| 当前 Mega USB 诊断方案 | Mega D51 | Mega D50 | **当前有效** | 以本行作为现行实物接线标准。 |
| 主 P4 日志/源代码注释（2026-07 阶段） | Mega D53 | Mega D52 | 历史记录/待核对 | `main.c` 的启动日志仍写 D53/D52；若实物已为 D51/D50，下一次维护主固件时应同步更正日志，不能把日志当作接线依据。 |
| 旧 P4 直连方案 | P4 GPIO25 | P4 GPIO26 | 已废弃/不使用 | `main/ultrasonic.c` 为旧直连代码；当前测距由 Mega 负责，不应将 HC-SR04 接回 P4。 |

## 9. Arduino Mega 2560：TCA9548A 与 4×VL53L1X

| 编号 | 信号 | Mega/TCA 端 | 设备端 | 状态 | 备注 |
|---|---|---|---|---|---|
| TOF-01 | I²C 主总线 SDA/SCL | Mega 默认 `Wire` I²C 引脚（Mega SDA=D20、SCL=D21） | TCA9548A SDA/SCL | 待实物复核 | 代码 `Wire.begin()`、100 kHz，TCA 地址 0x70；应在接线照片中标记 SDA/SCL。 |
| TOF-02 | 多路复用 | TCA9548A CH0 | VL53L1X #1 | 已确认（控制固件） | 控制固件数组为 CH0..CH3；与腿位映射仍需按实物逐一确认。 |
| TOF-03 | 多路复用 | TCA9548A CH1 | VL53L1X #2 | 已确认（控制固件） | 同上。 |
| TOF-04 | 多路复用 | TCA9548A CH2 | VL53L1X #3 | 已确认（控制固件） | 同上。 |
| TOF-05 | 多路复用 | TCA9548A CH3 | VL53L1X #4 | 已确认（控制固件） | 同上。 |
| TOF-06 | 供电 | Mega/TCA 供电 | 4×VL53L1X | 待实物复核 | 必须确认各模块电压、I²C 上拉电压与是否允许 5 V；不得仅根据代码猜测。 |

### VL53L1X 传感器—腿位映射（待实物确认）

项目腿序为：A1=RL，A2=RR，A3=FR，A4=FL。当前控制固件的数组顺序为 `FL, FR, RL, RR`，但 TCA CH0..CH3 与实际安装腿位的对应关系没有在现有资料中找到。完成逐腿测试后填写：

| TCA 通道 | 固件数组索引/暂定标签 | 实际腿位 | 传感器序列号/标签 | 已做伸缩方向验证 | 备注 |
|---:|---|---|---|---|---|
| CH0 | 索引 0 / 暂定 FL | 待确认 | 待填写 | 否 | |
| CH1 | 索引 1 / 暂定 FR | 待确认 | 待填写 | 否 | |
| CH2 | 索引 2 / 暂定 RL | 待确认 | 待填写 | 否 | |
| CH3 | 索引 3 / 暂定 RR | 待确认 | 待填写 | 否 | |

## 10. Arduino Mega 2560：四路推杆驱动信号

> **安全状态：当前 P4 主固件 `MEGA_ACTUATOR_COMMANDS_ENABLED=0`，运动命令禁止；本表记录的是 Mega 控制固件的已定义引脚，不构成运动授权。**

| 推杆/固件标签 | 项目腿序（待逐腿确认） | Mega IN1 | Mega IN2 | Mega EN | 驱动器端 | 状态 | 备注 |
|---|---|---:|---:|---:|---|---|---|
| 通道 0 / FL | A4=FL（待实物核对） | D22 | D23 | D30 | Driver 1 IN1/IN2/EN | 引脚已定义；实体对应待确认 | 代码数组索引 0。 |
| 通道 1 / FR | A3=FR（待实物核对） | D24 | D25 | D31 | Driver 2 IN1/IN2/EN | 引脚已定义；实体对应待确认 | 代码数组索引 1。 |
| 通道 2 / RL | A1=RL（待实物核对） | D26 | D27 | D32 | Driver 3 IN1/IN2/EN | 引脚已定义；实体对应待确认 | 代码数组索引 2。 |
| 通道 3 / RR | A2=RR（待实物核对） | D28 | D29 | D33 | Driver 4 IN1/IN2/EN | 引脚已定义；实体对应待确认 | 代码数组索引 3。 |

### 推杆驱动必填信息（尚缺）

| 项目 | 当前状态 | 必须补录内容 |
|---|---|---|
| 驱动器型号 | 未记录 | 型号、输入逻辑、EN 有效电平、是否内置限位与过流保护。 |
| 推杆型号 | 未记录 | 额定电压、最大电流、行程、内置限位/霍尔反馈情况。 |
| 动力电源 | 未记录 | 额定电压、最大电流、保险/断路器、主开关和急停路径。 |
| 实际通道-腿位 | 未完成 | 使用安全受限的单通道点动测试后，填写每路的真实腿位、伸出/缩回方向和 VL53L1X 对应通道。 |

## 11. 已废弃或禁止复用的 P4 推杆 GPIO 方案

| 旧方案 | P4 引脚 | 状态 | 禁止/风险原因 |
|---|---|---|---|
| FL PWM | GPIO5 / GPIO6 | 已废弃 | 当前执行器控制应由 Mega 统一处理；不要与其他 P4 外设混接。 |
| FR PWM | GPIO9 / GPIO10 | 已废弃 | 同上。 |
| RL PWM | GPIO11 / GPIO12 | 已废弃 | 同上。 |
| RR PWM | GPIO13 / GPIO14 | **禁止复用** | GPIO14 当前被 C6 SDIO D0 占用，接入会破坏 Wi-Fi/SDIO。 |
| P4 直连 HC-SR04 | GPIO25 / GPIO26 | 已废弃 | 当前 HC-SR04 应由 Mega D51/D50 驱动和读取。 |

## 12. 网络与控制台端口（非实体接线，但与数据链路相关）

| 服务 | 端口 | 当前约定 | 备注 |
|---|---:|---|---|
| 视频 TCP | 5000 | P4→PC JPEG 流 | 视频模式使用。 |
| IMU TCP | 5001 | P4→PC JSONL IMU 流 | IMU 模式使用；切换 IMU 后关闭 5000 并停止深度处理。 |
| 禁用端口 | 5002 | 不使用 | 不得另行启用。 |
| HTTP | 80 | P4 状态/接口 | 仅在需要时访问。 |

## 13. 每次更新的最小核对清单

1. 修改任何实体线缆前，先拍照并写下端点丝印；改线后将旧状态移入“历史/废弃”而不是直接删除。
2. 对 P4 GPIO：核对 `wifi_test/main/` 和 `sdkconfig`，确认没有占用冲突；特别检查 GPIO14（C6 SDIO D0）。
3. 对 Mega：核对实际烧录的 `.ino` 文件，而不是只看历史测试草稿。
4. 对 5V 设备：确认没有把 5V 信号接入 P4 的 3.3V GPIO；HC-SR04 ECHO 当前只能接 Mega D50。
5. 对推杆：确认动力电源、公共地、急停、限位、驱动器 EN 极性；未完成前维持软件安全锁。
6. 做不超过 3 秒的短测并保存串口日志；将测试时间、结果和异常添加到下表。
7. 同步更新本文件的“状态”“备注”和“变更记录”。

## 14. 变更记录

| 日期/时间 | 修改人 | 范围 | 变更内容 | 依据/验证 | 结果 |
|---|---|---|---|---|---|
| 2026-08-07 23:04 CST | Hermes（GPT-5.6 Luna） | 全系统 | 建立接线总表；汇总 P4 相机、BNO085、C6 SDIO、USB-Mega、HC-SR04、TCA9548A/VL53L1X、推杆信号及历史冲突。 | 当前项目源代码与既有已确认结论；未能从代码确认的部分明确标为“待实物复核”。 | 文档建立，后续持续维护。 |

---

## 附：主要源码依据

- `wifi_test/main/camera.c`：OV5647 相机 SCCB/I²C、XCLK 与 CSI 配置。
- `wifi_test/main/imu.c`：BNO085 UART-RVC 模式和 GPIO3（UART1 RX）。
- `wifi_test/sdkconfig`：P4↔C6 SDIO GPIO18/19/14/15/16/17 以及 GPIO54 reset。
- `wifi_test/main/mega_sr04.c`、`wifi_test/main/main.c`：P4 USB Host/CH340/Mega 集成和软件安全锁状态。
- `usb_cdc_mega_test/mega_sr04_bridge_diagnostic/mega_sr04_bridge_diagnostic.ino`：现行 HC-SR04 D51/D50/5V/GND 诊断接线。
- `usb_cdc_mega_test/mega_lander_actuator_controller/mega_lander_actuator_controller.ino`：TCA9548A（0x70）、VL53L1X CH0..CH3、推杆控制 D22..D33。

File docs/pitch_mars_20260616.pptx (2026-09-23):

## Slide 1

Advanced Subsystems for

Martian Exploration

6 Innovative Engineering Concepts for Lander & Rover Survivability

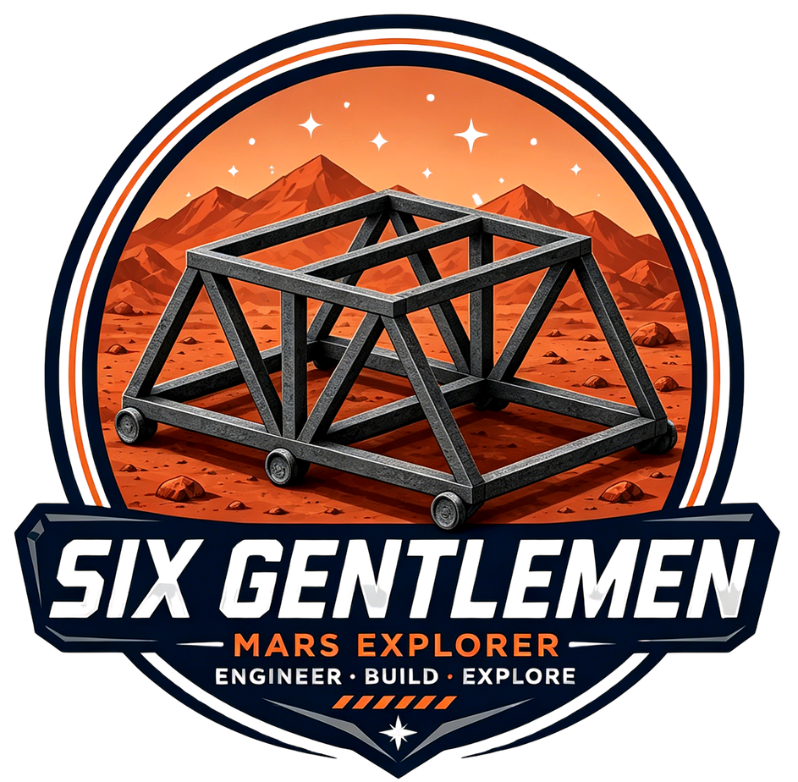
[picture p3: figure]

Course: ENGR1000J

Instructor: Prof. Shen & Prof. Wei

Presenter: Group 5

Group Name: six gentlemen

SJTU Global College — Technical Communication Pitch

1

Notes: Hello everyone, we are Group Five, the Six Gentlemen from SJTU Global College. Today, we are very excited to present our technical pitch, focusing on advanced engineering subsystems designed for Mars exploration missions. We will walk you through five innovative concepts aimed at improving the survivability and efficiency of planetary landers and rovers in hostile space environments. Let us begin.

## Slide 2

Six Innovative Space Exploration Concepts

Overview: Five specialized subsystems engineered to address critical environmental challenges on Mars

01 | Deep Space Thermal Control System

Closed-loop PID loops maintaining internal instrumentation.

04 | Adaptive Robotic Arm Gripper

Soft-robotic claw conforming to irregular minerals.

02 | Self-Stabilizing Landing Platform

Active-leveling landing legs to prevent spacecraft tipping.

05 | Deployable Communication Relays

Micro launcher bridging signals over steep canyons.

03 | Quadrupedal Wheeled Mars Rover

A wheeled quadruped robot that keeps its body level on any terrain.

06 | Electrostatic Solar Dust Remover

Dynamic traveling electric fields clearing panel dust.

Group 5 | six gentlemen

2

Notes: On this slide, you can see an overview of the five specialized subsystems we have developed. We will first discuss our self-stabilizing landing platform, which uses active suspension. Next, we will cover our adaptive robotic arm gripper for specimen collection. Then, we will look at high-precision deep space thermal control. After that, we will introduce deployable micro communication relays, and finally, we will present our electrostatic dust removal device for solar panels. Each system solves a critical threat to mission success.

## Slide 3

01 | Deep Space Thermal Control System

Problem:

Extreme temperatures in deep space alternate between direct solar heat and cryogenic shadows, destroying delicate electronics.

A closed-loop thermal regulation system with high-precision control to maintain a constant internal temperature for instrumentation.

Figure 1: High-precision thermal regulation system layout for deep space instrumentation cabinets.

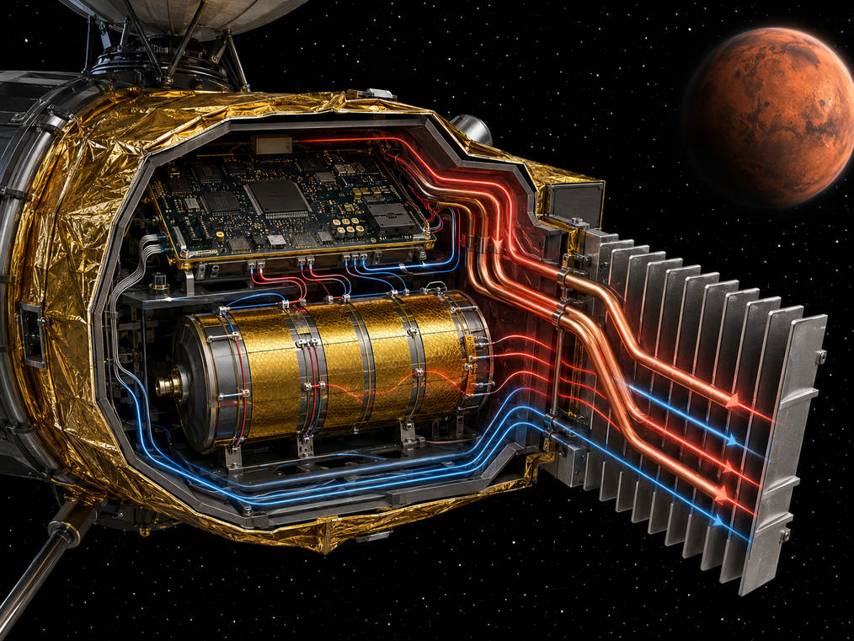
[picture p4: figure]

Need:

Solution:

PID-controlled loops combining heater patches, heatsinks, heat pipes, and insulation layers, achieving +/- 1 degree Celsius stability.

Group 5 | six gentlemen

5

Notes: Our third concept is the Deep Space Thermal Control System. Explorers experience severe temperature variations in vacuum, alternating between direct sunlight and cryogenic shadows. Sensitive electronics will break outside narrow thermal boundaries. We need closed-loop thermal regulation with high-precision feedback. Our solution utilizes heaters, heat pipes, and multilayer insulation blankets. Using PID control, the system maintains the electronics bay temperature within a strict range of plus or minus one degree Celsius.

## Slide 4

02 | Self-Stabilizing Landing Platform

Problem:

Landing on uneven slopes or crater rims tilts or tips over spacecraft, causing structural damage or blocking rover release.

Figure 2: Concept design of the self-stabilizing lander utilizing active suspension on a steep Martian slope.

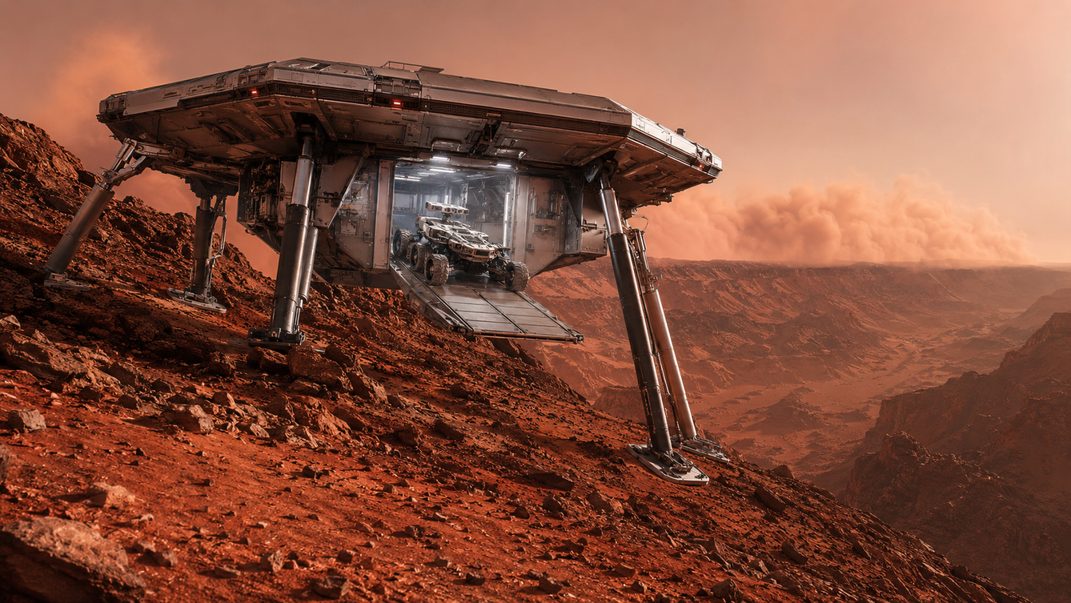
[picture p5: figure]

Need:

An active self-leveling landing system to keep the main deck perfectly horizontal on highly uneven terrains.

Solution:

Active suspension with four telescopic legs, IMU sensors, and parallel inverse kinematics to level the landing platform.

Group 5 | six gentlemen

3

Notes: First, let us examine the Self-Stabilizing Landing Platform. Landing on uneven Martian slopes or rocky crater edges is extremely hazardous. Typical landers can easily tip over, causing structural failure or permanently trapping the rover inside. To address this need, our solution integrates active suspension with four telescopic legs and real-time IMU sensors. By applying parallel inverse kinematics, the legs dynamically adjust their lengths on touchdown to keep the main deck perfectly level, ensuring a safe rover deployment.
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

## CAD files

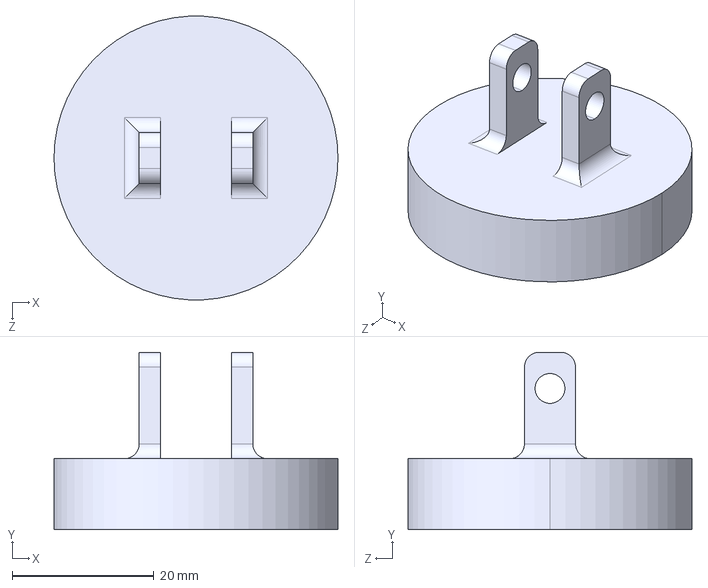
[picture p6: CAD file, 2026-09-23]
CAD/缓冲件.STEP
40.0 x 25.0 x 39.9 mm

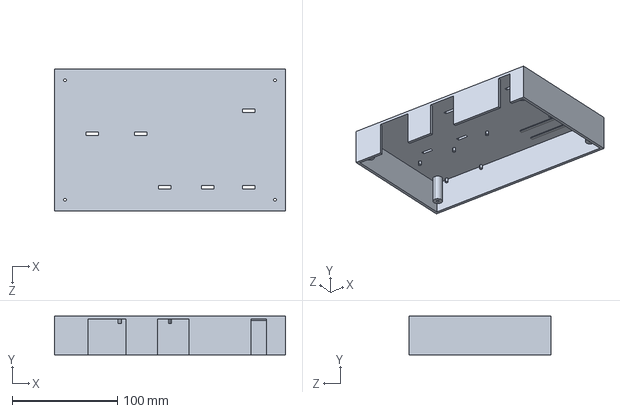
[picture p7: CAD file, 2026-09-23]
project/mechanical/2026-07-26-control-box-v1/mars_lander_control_box_base_v1p1.step
220.0 x 37.0 x 135.0 mm

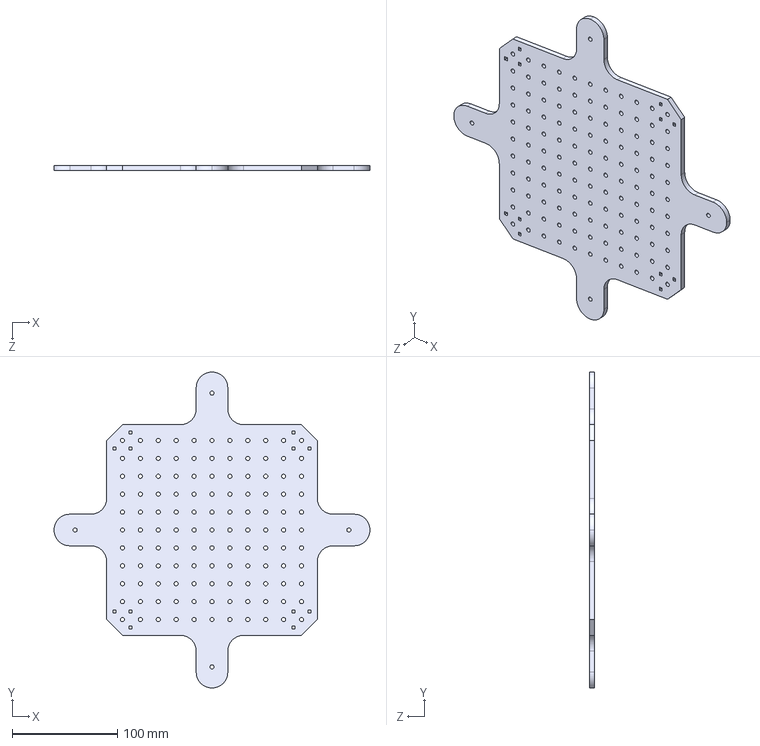
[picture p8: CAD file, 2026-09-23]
CAD/亚克力板.STEP
300.0 x 300.0 x 5.00 mm

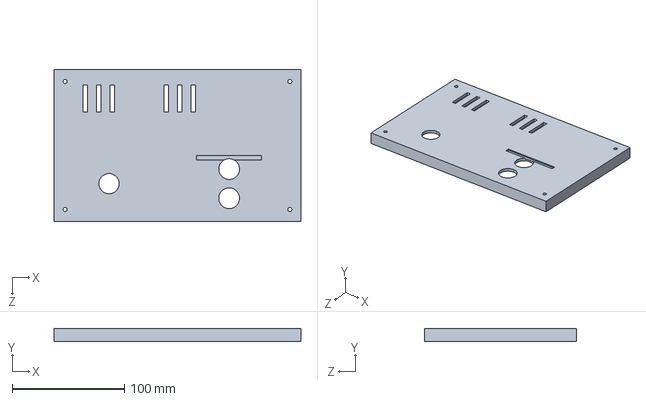
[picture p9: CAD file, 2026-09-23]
project/mechanical/2026-07-26-control-box-v1/mars_lander_control_box_lid_v1p2.step
220.0 x 12.0 x 135.0 mm

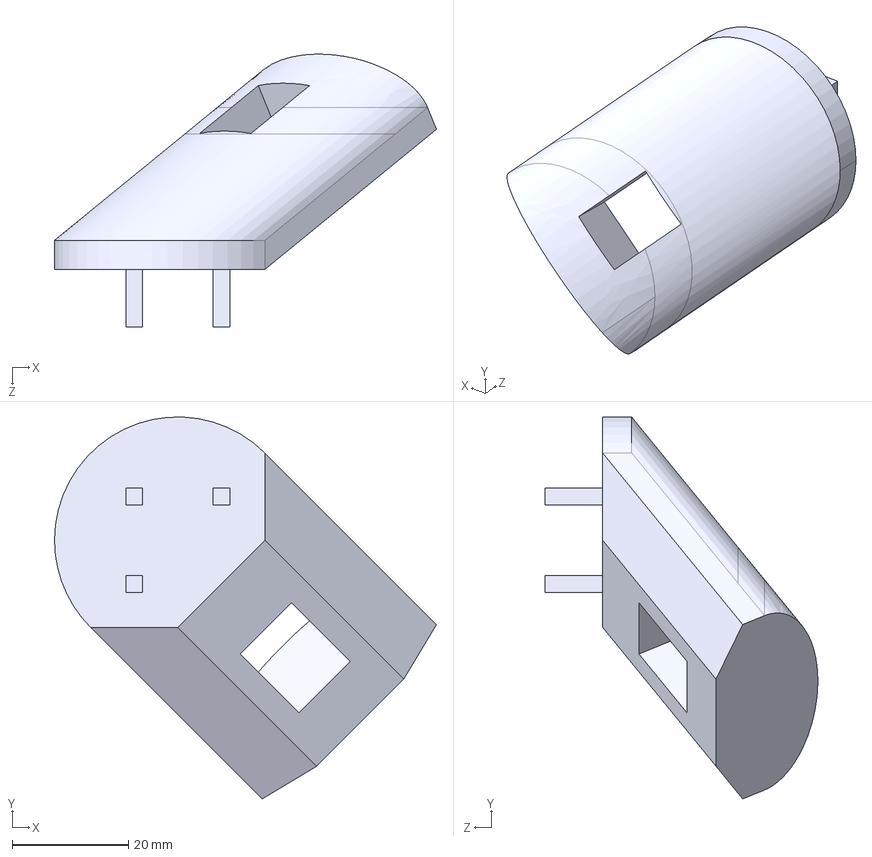
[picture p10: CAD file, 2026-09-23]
CAD/推杆固定件v2.STEP
65.7 x 65.7 x 46.9 mm

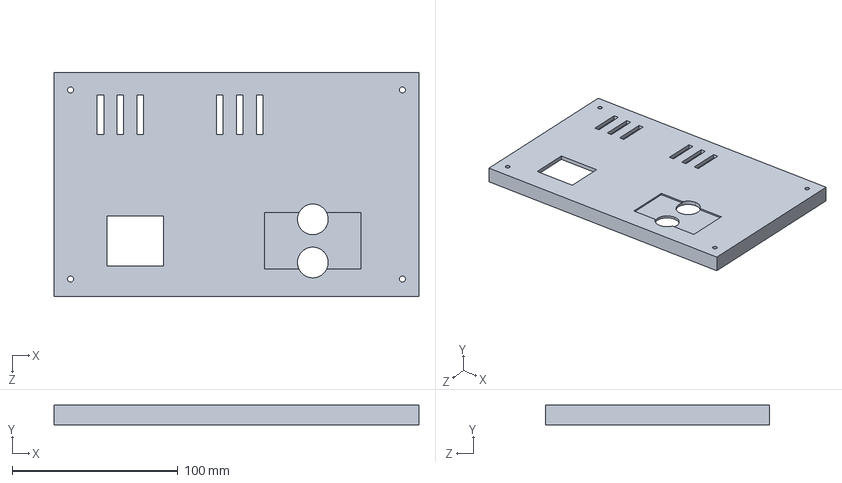
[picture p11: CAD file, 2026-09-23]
project/mechanical/2026-07-26-control-box-v1/mars_lander_control_box_lid_v1.step
220.0 x 12.0 x 135.0 mm

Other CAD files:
project/mechanical/2026-07-26-control-box-v1/mars_lander_control_box_lid_v1p1.step
project/mechanical/2026-07-26-control-box-v1/mars_lander_control_box_base_v1.step
project/mechanical/2026-07-26-control-box-v1/mars_lander_control_box_base_v1p2.step
project/mechanical/2026-07-26-control-box-v1/mars_lander_control_box_base_v1p3.step
project/mechanical/2026-07-26-control-box-v1/mars_lander_control_box_lid_v1p3.step
project/mechanical/2026-07-26-control-box-v1/mars_lander_control_box_base_v1.SLDPRT
project/mechanical/2026-07-26-control-box-v1/mars_lander_control_box_base_v1.STL
project/mechanical/2026-07-26-control-box-v1/mars_lander_control_box_base_v1p1.SLDPRT
project/mechanical/2026-07-26-control-box-v1/mars_lander_control_box_base_v1p1.STL
project/mechanical/2026-07-26-control-box-v1/mars_lander_control_box_base_v1p2.SLDPRT
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

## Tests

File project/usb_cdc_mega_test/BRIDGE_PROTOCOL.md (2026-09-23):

# P4 ↔ PC ↔ Mega framed bridge protocol (v1)

This protocol runs over the P4's `COM5` UART0 connection. It is deliberately
**not** a raw Arduino serial port: opening COM5 must not allow an IDE/uploader
to toggle P4's auto-reset lines.

## Frame format

All multi-byte integers are little-endian.

```text
SOF0  SOF1  TYPE  LENGTH_LO  LENGTH_HI  PAYLOAD[0..LENGTH-1]  CRC_LO  CRC_HI
0xA5  0x5A  u8    u16 LE                         variable       CRC16-CCITT
```

CRC16-CCITT parameters: initial `0xFFFF`, polynomial `0x1021`; CRC covers
`TYPE | LENGTH_LO | LENGTH_HI | PAYLOAD`, not SOF bytes. The maximum payload is
512 bytes. The receiver must discard malformed frames and resynchronize on
`A5 5A`.

## PC → P4 commands

| Type | Name | Payload | P4 behavior |
|---:|---|---|---|
| `0x01` | HELLO | empty | Responds `HELLO_ACK`; client uses this after clearing early boot text. |
| `0x10` | MEGA_TX | 1–256 raw bytes | Writes bytes to Mega CH340 UART, if connected. |
| `0x12` | SET_LINE | `u32 baud`, `u8 stop_bits`, `u8 parity`, `u8 data_bits` | Applies CH340 line coding. Mega bootloader uses `115200,0,0,8`. |
| `0x13` | SET_CONTROL | `u8 flags`: bit0 DTR, bit1 RTS | Applies CH340 DTR/RTS. |
| `0x14` | RESET_MEGA | empty | Pulses CH340 DTR low then high. It is only a reset request; it never writes Mega flash. |
| `0x15` | GET_STATUS | empty | Replies with `STATUS`. |

## P4 → PC responses

| Type | Name | Payload |
|---:|---|---|
| `0x02` | HELLO_ACK | `"P4MEGA1"` plus status flags |
| `0x11` | MEGA_RX | Raw bytes received from Mega. |
| `0x16` | STATUS | connection state and last ESP error code. |
| `0x7F` | ERROR | `u8 command_type`, `i32 esp_err_t` |

## Boundary

This bridge does not implement STK500v2, does not store a Mega image, and does
not autonomously flash Mega. A PC-side uploader can use `MEGA_TX` / `MEGA_RX`
after requesting `SET_LINE` and `RESET_MEGA`.

Do not use a generic Arduino IDE serial upload directly against COM5. It can
toggle the P4's own UART control lines and reset the P4.

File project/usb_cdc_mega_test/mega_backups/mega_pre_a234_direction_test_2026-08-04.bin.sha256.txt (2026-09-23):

D29CD09550822474538D89FF49B82F37DD6209CE0F54B596813DEC809A979A82  mega_pre_a234_direction_test_2026-08-04.bin

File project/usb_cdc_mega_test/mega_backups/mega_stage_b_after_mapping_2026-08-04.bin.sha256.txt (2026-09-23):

BAE509BE2EEA52BD3BC39DB3FEFE82FA9F670FFC0AD9F56353BCA7FBCCDBA023  mega_stage_b_after_mapping_2026-08-04.bin

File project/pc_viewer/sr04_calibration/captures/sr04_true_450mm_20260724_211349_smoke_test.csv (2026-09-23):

capture_utc | true_mm | label | frame_id | jpeg_timestamp_us | sr04_distance_mm | pulse_us | status | valid | sample_age_us | mega_connected
2026-07-24T13:13:49.946Z | 450.0 | smoke_test | 64 | 2575554853 | -1 | 46667 | echo_too_long | 0 | 50061 | 1
2026-07-24T13:13:50.147Z | 450.0 | smoke_test | 65 | 2575704450 | -1 | 46667 | echo_too_long | 0 | 199659 | 1
2026-07-24T13:13:50.249Z | 450.0 | smoke_test | 66 | 2575858454 | -1 | 46660 | echo_too_long | 0 | 153675 | 1
2026-07-24T13:13:50.508Z | 450.0 | smoke_test | 67 | 2576113922 | -1 | 46664 | echo_too_long | 0 | 9853 | 1
2026-07-24T13:13:50.611Z | 450.0 | smoke_test | 68 | 2576227622 | -1 | 46664 | echo_too_long | 0 | 123562 | 1
2026-07-24T13:13:50.760Z | 450.0 | smoke_test | 69 | 2576332704 | -1 | 46671 | echo_too_long | 0 | 27820 | 1
2026-07-24T13:13:50.865Z | 450.0 | smoke_test | 70 | 2576433645 | -1 | 46671 | echo_too_long | 0 | 128765 | 1
2026-07-24T13:13:50.923Z | 450.0 | smoke_test | 71 | 2576538286 | -1 | 46666 | echo_too_long | 0 | 33549 | 1
2026-07-24T13:13:51.072Z | 450.0 | smoke_test | 72 | 2576639131 | -1 | 46666 | echo_too_long | 0 | 134395 | 1
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

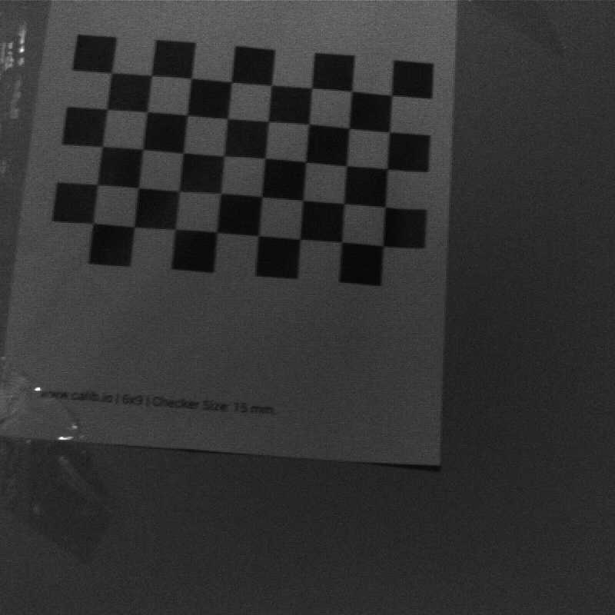
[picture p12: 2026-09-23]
project/wifi_test/calibration_runs/2026-07-24-ov5647-intrinsics-8x5-20mm/views/view_010.png

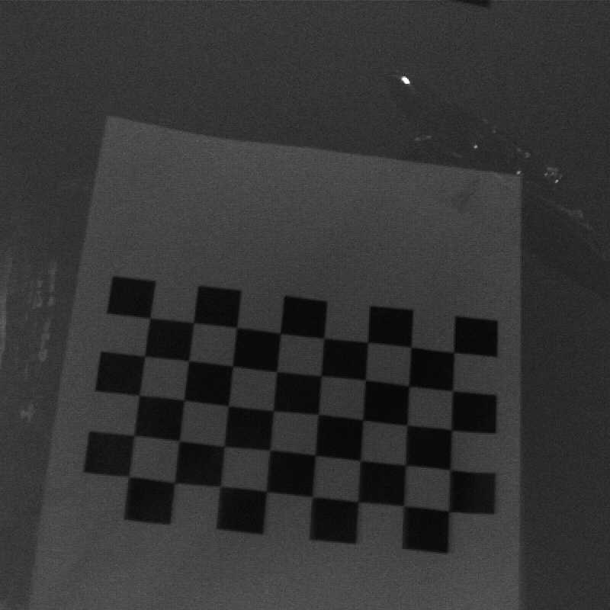
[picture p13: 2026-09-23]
project/wifi_test/calibration_runs/2026-07-24-ov5647-intrinsics-8x5-20mm/views/view_012.png

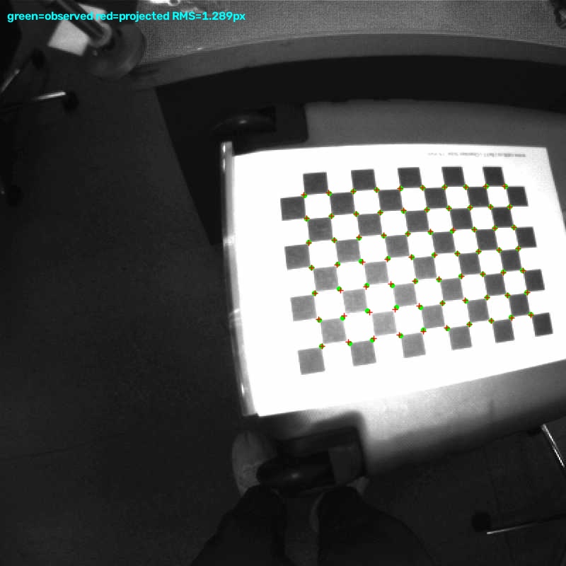
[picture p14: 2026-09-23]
project/wifi_test/calibration_runs/2026-08-04-fisheye-10x7-15mm/audit/view_036_reprojection.jpg

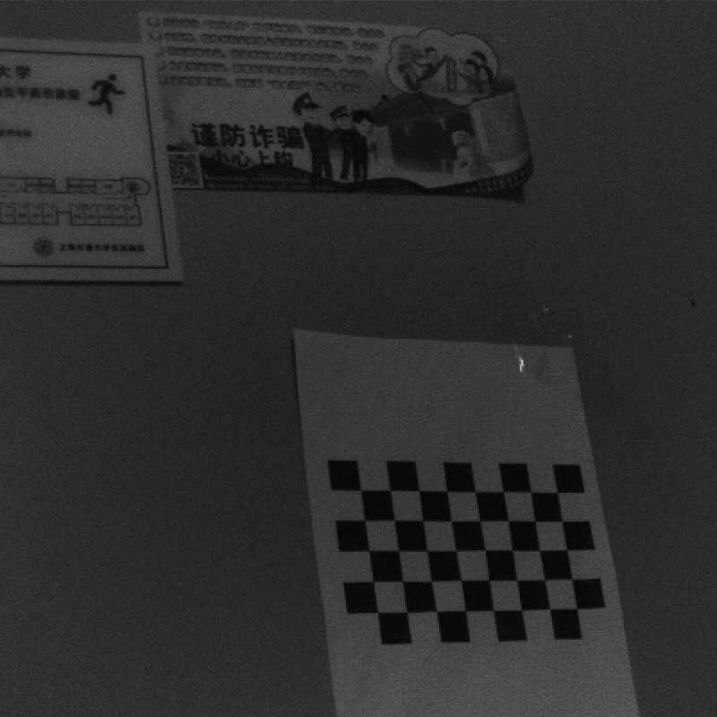
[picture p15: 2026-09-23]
project/wifi_test/calib_frames/calib_016.jpg

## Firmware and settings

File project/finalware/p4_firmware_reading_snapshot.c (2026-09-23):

/*
 * Mars Lander ESP32-P4 Firmware — Reading/Archive Snapshot
 *
 * Purpose: one-file, human-readable archival view of the source files compiled
 * into the saved ESP32-P4 production application.
 *
 * IMPORTANT: This is NOT a build input and must NOT replace wifi_test/main/.
 * The active firmware is intentionally split into modules. Concatenating these
 * modules preserves their text for reading, but makes duplicate module-private
 * static symbols share one C translation unit and therefore is not directly
 * compilable. Build the original modular source tree instead.
 *
 * Active ESP-IDF source units: main.c, camera.c, imu.c, mega_sr04.c, actuator.c.
 * Excluded: ultrasonic.c/.h because it is not listed in the active
 * idf_component_register(SRCS ...) entry; HC-SR04 is currently owned by Mega.
 * The project-level CMakeLists.txt was excluded from this source-only finalware
 * snapshot because it is build configuration, not a C/C++ source unit.
 */


/* ============================================================================
 * BEGIN ORIGINAL FILE: wifi_test/main/idf_component.yml
 * SHA256 (UTF-8 source): bb60363a5a36b0ed45f8c4fb9246ed57018bb95764b80f13787754c3b3ca91ca
 * ========================================================================== */

dependencies:
  idf: ">=5.4"
  # P4 + C6 SDIO stack pinned to the previously stable local combination.
  # New esp_hosted 2.12.11 asserted during early Hosted task creation on this board.
  espressif/esp_hosted: "1.4.7"
  espressif/esp_wifi_remote: "0.14.5"
  espressif/usb_host_ch34x_vcp: "2.2.1"

/* ============================================================================
 * END ORIGINAL FILE: wifi_test/main/idf_component.yml
 * ========================================================================== */

/* ============================================================================
 * BEGIN ORIGINAL FILE: wifi_test/main/camera.h
 * SHA256 (UTF-8 source): 22bbe631136f94cab9509c7643939aefe0597880d9ce4c5a62235848d3dea15c
 * ========================================================================== */

/*
 * OV5647 MIPI CSI Camera Driver - ESP-IDF
 */

#ifndef CAMERA_H
#define CAMERA_H

#include "esp_err.h"
#include <stdint.h>
#include <stdbool.h>
#include <stddef.h>

esp_err_t camera_init(void);
esp_err_t camera_start(void);
esp_err_t camera_stop(void);
uint8_t *camera_get_frame(size_t *out_len, uint32_t timeout_ms);
bool camera_is_ready(void);
uint32_t camera_get_width(void);
uint32_t camera_get_height(void);

#endif

/* ============================================================================
 * END ORIGINAL FILE: wifi_test/main/camera.h
 * ========================================================================== */

/* ============================================================================
 * BEGIN ORIGINAL FILE: wifi_test/main/camera.c
 * SHA256 (UTF-8 source): 00ee4db63c704c7c1b6def478ba0e9ac34da3bcc335262a2f37774271065f392
 * ========================================================================== */

/*
 * OV5647 MIPI CSI Camera Driver - ESP-IDF
 * XCLK: GPIO40 (P4 clock router)  I2C: GPIO7(SDA), GPIO8(SCL)
 * 1920x1080 or 1280x720, PSRAM对齐缓冲
 *
 * 流程: LDO → XCLK → I2C → SCCB → 检测传感器 → 设置格式 → 启动流 → CSI → ISP
 */

#include <string.h>
#include <inttypes.h>
#include "freertos/FreeRTOS.h"
#include "freertos/semphr.h"
#include "esp_log.h"
#include "esp_err.h"
#include "esp_cam_sensor_xclk.h"
#include "esp_cam_sensor.h"
#include "esp_cam_sensor_detect.h"
#include "esp_cam_sensor_types.h"
#include "esp_sccb_i2c.h"
#include "esp_cam_ctlr.h"
#include "esp_cam_ctlr_csi.h"
#include "esp_ldo_regulator.h"
#include "driver/i2c_master.h"
#include "driver/isp.h"
#include "esp_heap_caps.h"
#include "camera.h"

static const char *TAG = "CAM";

// 引脚
#define CAM_I2C_PORT        0
#define CAM_I2C_SDA_PIN     7
#define CAM_I2C_SCL_PIN     8
#define CAM_I2C_FREQ        100000
#define CAM_XCLK_PIN        40
#define CAM_XCLK_FREQ       24000000
#define CAM_CSI_LDO_CHAN    3
#define CAM_CSI_LDO_MV      2500
#define CAM_CSI_DATA_LANES  2

// 状态
static esp_cam_ctlr_handle_t s_cam_handle = NULL;
static esp_cam_sensor_xclk_handle_t s_xclk_handle = NULL;
static esp_ldo_channel_handle_t s_ldo_handle = NULL;
static isp_proc_handle_t s_isp_handle = NULL;
static i2c_master_bus_handle_t s_i2c_bus = NULL;
static esp_sccb_io_handle_t s_sccb_handle = NULL;
static esp_cam_sensor_device_t *s_sensor_dev = NULL;
static uint8_t *s_frame_buffer = NULL;
static size_t s_frame_size = 0;
static SemaphoreHandle_t s_frame_ready = NULL;
static uint8_t *s_latest_frame = NULL;
static size_t s_latest_frame_len = 0;
static bool s_initialized = false;
static uint32_t s_width = 0;
static uint32_t s_height = 0;

// CSI回调
static bool IRAM_ATTR on_get_new_trans(esp_cam_ctlr_handle_t handle,
                                        esp_cam_ctlr_trans_t *trans, void *user_data)
{
    trans->buffer = s_frame_buffer;
    trans->buflen = s_frame_size;
    return false;
}

static bool IRAM_ATTR on_trans_finished(esp_cam_ctlr_handle_t handle,
                                         esp_cam_ctlr_trans_t *trans, void *user_data)
{
    s_latest_frame = (uint8_t *)trans->buffer;
    s_latest_frame_len = trans->received_size;
    BaseType_t xHigherPriorityTaskWoken = pdFALSE;
    xSemaphoreGiveFromISR(s_frame_ready, &xHigherPriorityTaskWoken);
    // 注意: IRAM_ATTR回调里不能用ESP_LOG, 但可以设置标记
    return xHigherPriorityTaskWoken;
}

// 检测传感器
static esp_cam_sensor_device_t *detect_sensor(esp_cam_sensor_config_t *cfg)
{
    esp_cam_sensor_detect_fn_t *start = NULL;
    esp_cam_sensor_detect_fn_t *end = NULL;
    esp_cam_sensor_detect_get_array(&start, &end);

    for (esp_cam_sensor_detect_fn_t *fn = start; fn < end; fn++) {
        if (fn->detect) {
            esp_cam_sensor_device_t *dev = fn->detect(cfg);
            if (dev) {
                ESP_LOGI(TAG, "Sensor detected via: port=%d, addr=0x%02X", fn->port, fn->sccb_addr);
                return dev;
            }
        }
    }
    return NULL;
}

esp_err_t camera_init(void)
{
    if (s_initialized) return ESP_OK;
    esp_err_t ret;

    s_frame_ready = xSemaphoreCreateBinary();
    ESP_LOGI(TAG, "Initializing camera...");

    // Step 1: LDO 2.5V for MIPI PHY
    esp_ldo_channel_config_t ldo_cfg = { .chan_id = CAM_CSI_LDO_CHAN, .voltage_mv = CAM_CSI_LDO_MV };
    ret = esp_ldo_acquire_channel(&ldo_cfg, &s_ldo_handle);
    if (ret != ESP_OK) { ESP_LOGE(TAG, "LDO failed: 0x%x", ret); return ret; }
    vTaskDelay(pdMS_TO_TICKS(10));

    // Step 2: P4 dedicated clock router produces 24 MHz XCLK. This avoids
    // consuming LEDC resources needed by future actuator PWM.
    esp_cam_sensor_xclk_config_t xclk_cfg = {
        .esp_clock_router_cfg = {
            .xclk_freq_hz = CAM_XCLK_FREQ,
            .xclk_pin = CAM_XCLK_PIN,
        },
    };
    ret = esp_cam_sensor_xclk_allocate(ESP_CAM_SENSOR_XCLK_ESP_CLOCK_ROUTER, &s_xclk_handle);
    if (ret != ESP_OK) { ESP_LOGE(TAG, "XCLK router alloc failed: 0x%x", ret); return ret; }
    ret = esp_cam_sensor_xclk_start(s_xclk_handle, &xclk_cfg);
    if (ret != ESP_OK) { ESP_LOGE(TAG, "XCLK router start failed: 0x%x", ret); return ret; }
    vTaskDelay(pdMS_TO_TICKS(20));
    ESP_LOGI(TAG, "XCLK router 24MHz OK");

    // Step 3: I2C bus
    i2c_master_bus_config_t i2c_cfg = {
        .i2c_port = CAM_I2C_PORT, .sda_io_num = CAM_I2C_SDA_PIN, .scl_io_num = CAM_I2C_SCL_PIN,
        .clk_source = I2C_CLK_SRC_DEFAULT, .glitch_ignore_cnt = 7,
        .intr_priority = 0, .trans_queue_depth = 0, .flags = { .enable_internal_pullup = 1 },
    };
    ret = i2c_new_master_bus(&i2c_cfg, &s_i2c_bus);
    if (ret != ESP_OK) { ESP_LOGE(TAG, "I2C failed: 0x%x", ret); return ret; }

    // Step 4: SCCB I2C IO (sensor I2C handle)
    sccb_i2c_config_t sccb_cfg = {
        .dev_addr_length = I2C_ADDR_BIT_LEN_7,
        .device_address = 0x36,  // OV5647 default
        .scl_speed_hz = CAM_I2C_FREQ,
        .addr_bits_width = 16,   // OV5647 uses 16-bit register addresses
        .val_bits_width = 8,     // 8-bit register values
    };
    ret = sccb_new_i2c_io(s_i2c_bus, &sccb_cfg, &s_sccb_handle);
    if (ret != ESP_OK) { ESP_LOGE(TAG, "SCCB init failed: 0x%x", ret); return ret; }

    // Step 5: 检测传感器
    esp_cam_sensor_config_t sensor_cfg = {
        .sccb_handle = s_sccb_handle,
        .reset_pin = -1,
        .pwdn_pin = -1,
        .xclk_pin = -1,       // XCLK is configured separately through P4 clock router
        .xclk_freq_hz = 0,
        .sensor_port = ESP_CAM_SENSOR_MIPI_CSI,
    };
    s_sensor_dev = detect_sensor(&sensor_cfg);
    if (!s_sensor_dev) {
        ESP_LOGE(TAG, "No camera sensor detected!");
        ESP_LOGI(TAG, "Check: CSI cable, XCLK(GPIO40), I2C(GPIO7/8)");
        return ESP_ERR_NOT_FOUND;
    }
    ESP_LOGI(TAG, "Sensor: %s", esp_cam_sensor_get_name(s_sensor_dev));

    // Step 6: 查询格式，优先选1080p
    esp_cam_sensor_format_array_t fmt_array = {0};
    ret = esp_cam_sensor_query_format(s_sensor_dev, &fmt_array);
    if (ret != ESP_OK) {
        ESP_LOGE(TAG, "Query format failed: 0x%x", ret);
        return ret;
    }

    const esp_cam_sensor_format_t *selected_fmt = NULL;
    ESP_LOGI(TAG, "Available formats (%" PRIu32 "):", fmt_array.count);
    for (int i = 0; i < fmt_array.count; i++) {
        const esp_cam_sensor_format_t *f = &fmt_array.format_array[i];
        ESP_LOGI(TAG, "  [%d] %s %dx%d", i, f->name ? f->name : "?", f->width, f->height);
        // 优先1080p
        if (f->height == 1080 && !selected_fmt) selected_fmt = f;
    }
    // fallback to 720p
    if (!selected_fmt) {
        for (int i = 0; i < fmt_array.count; i++) {
            if (fmt_array.format_array[i].height == 720) {
                selected_fmt = &fmt_array.format_array[i];
                break;
            }
        }
    }
    // fallback to first
    if (!selected_fmt && fmt_array.count > 0) {
        selected_fmt = &fmt_array.format_array[0];
    }

    if (!selected_fmt) {
        ESP_LOGE(TAG, "No format available!");
        return ESP_ERR_NOT_FOUND;
    }

    s_width = selected_fmt->width;
    s_height = selected_fmt->height;
    ESP_LOGI(TAG, "Selected: %s %" PRIu32 "x%" PRIu32, selected_fmt->name ? selected_fmt->name : "?", s_width, s_height);

    ret = esp_cam_sensor_set_format(s_sensor_dev, selected_fmt);
    if (ret != ESP_OK) { ESP_LOGE(TAG, "Set format failed: 0x%x", ret); return ret; }

    // Step 7: 启动传感器数据流
    bool stream_on = true;
    ret = esp_cam_sensor_ioctl(s_sensor_dev, ESP_CAM_SENSOR_IOC_S_STREAM, &stream_on);
    if (ret != ESP_OK) { ESP_LOGE(TAG, "Start stream failed: 0x%x", ret); return ret; }
    ESP_LOGI(TAG, "Sensor streaming ON");

    // Step 8: CSI控制器
    esp_cam_ctlr_csi_config_t csi_cfg = {
        .ctlr_id = 0, .h_res = s_width, .v_res = s_height,
        .data_lane_num = CAM_CSI_DATA_LANES, .lane_bit_rate_mbps = 200,
        .input_data_color_type = CAM_CTLR_COLOR_RAW8, .output_data_color_type = CAM_CTLR_COLOR_RGB565,
        .queue_items = 1, .bk_buffer_dis = true, .byte_swap_en = false,
    };
    ret = esp_cam_new_csi_ctlr(&csi_cfg, &s_cam_handle);
    if (ret != ESP_OK) { ESP_LOGE(TAG, "CSI failed: 0x%x", ret); return ret; }

    esp_cam_ctlr_evt_cbs_t cbs = { .on_get_new_trans = on_get_new_trans, .on_trans_finished = on_trans_finished };
    esp_cam_ctlr_register_event_callbacks(s_cam_handle, &cbs, NULL);

    // Step 9: 帧缓冲 (PSRAM, 64字节对齐)
    s_frame_size = s_width * s_height * 2;
    s_frame_buffer = heap_caps_aligned_alloc(64, s_frame_size, MALLOC_CAP_SPIRAM);
    if (!s_frame_buffer) s_frame_buffer = heap_caps_malloc(s_frame_size, MALLOC_CAP_SPIRAM);
    if (!s_frame_buffer) { ESP_LOGE(TAG, "Buffer alloc failed! (%zuKB)", s_frame_size/1024); return ESP_ERR_NO_MEM; }
    memset(s_frame_buffer, 0, s_frame_size);
    ESP_LOGI(TAG, "Buffer: %zuKB @ %p (%" PRIu32 "x%" PRIu32 " RGB565)", s_frame_size/1024, s_frame_buffer, s_width, s_height);

    // Step 10: ISP (RAW8 → RGB565)
    esp_isp_processor_cfg_t isp_cfg = {
        .clk_hz = 80000000, .input_data_source = ISP_INPUT_DATA_SOURCE_CSI,
        .input_data_color_type = ISP_COLOR_RAW8, .output_data_color_type = ISP_COLOR_RGB565,
        .has_line_start_packet = false, .has_line_end_packet = false,
        .h_res = s_width, .v_res = s_height,
    };
    ret = esp_isp_new_processor(&isp_cfg, &s_isp_handle);
    if (ret != ESP_OK) { ESP_LOGE(TAG, "ISP failed: 0x%x", ret); return ret; }
    esp_isp_enable(s_isp_handle);

    // Step 11: 使能CSI
    esp_cam_ctlr_enable(s_cam_handle);

    s_initialized = true;
    ESP_LOGI(TAG, "Camera ready! %" PRIu32 "x%" PRIu32, s_width, s_height);
    return ESP_OK;
}

esp_err_t camera_start(void) { return s_initialized ? esp_cam_ctlr_start(s_cam_handle) : ESP_ERR_INVALID_STATE; }
esp_err_t camera_stop(void) { return s_initialized ? esp_cam_ctlr_stop(s_cam_handle) : ESP_ERR_INVALID_STATE; }

uint8_t *camera_get_frame(size_t *out_len, uint32_t timeout_ms)
{
    if (!s_initialized) return NULL;
    if (timeout_ms > 0 && xSemaphoreTake(s_frame_ready, pdMS_TO_TICKS(timeout_ms)) != pdTRUE) return NULL;
    if (out_len) *out_len = s_latest_frame_len;
    return s_latest_frame;
}
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
void app_main(void)
{
    s_boot_time = esp_timer_get_time();
    ESP_LOGI(TAG, "Mars Lander - Camera + WiFi + IMU UART-RVC + Act");
    ESP_LOGI(TAG, "  Video TCP: port %d (4B LE len + JPEG)", PC_PORT);
    ESP_LOGI(TAG, "  IMU TCP: port %d (independent JSONL sample stream)", IMU_TCP_PORT);
    ESP_LOGI(TAG, "  UART-RVC:  UART%d RX=GPIO%d, %d baud, 19-byte frames",
             1, 3, 115200);
    ESP_LOGI(TAG, "  Timestamps: esp_timer_get_time() us since boot");

    esp_err_t ret = nvs_flash_init();
    if (ret == ESP_ERR_NVS_NO_FREE_PAGES || ret == ESP_ERR_NVS_NEW_VERSION_FOUND) {
        ESP_ERROR_CHECK(nvs_flash_erase());
        ret = nvs_flash_init();
    }
    ESP_ERROR_CHECK(ret);

    // UART-RVC must begin consuming its continuous 100 Hz stream before slow
    // WiFi/camera bring-up. This mirrors the proven standalone imu_test path.
    s_imu_mutex = xSemaphoreCreateMutex();
    if (!s_imu_mutex) {
        ESP_LOGE(TAG, "IMU mutex allocation failed");
        return;
    }
    ret = imu_init();
    if (ret != ESP_OK) {
        ESP_LOGW(TAG, "IMU init failed: 0x%x (continuing without IMU)", ret);
    }

    ret = wifi_init_sta();
    if (ret != ESP_OK) {
        ESP_LOGE(TAG, "WiFi init failed: 0x%x; restarting for bounded recovery", ret);
        vTaskDelay(pdMS_TO_TICKS(5000));
        esp_restart();
    }
    xTaskCreate(network_supervisor_task, "net_super", 4096, NULL, 4, NULL);
    ESP_LOGI(TAG, "WiFi supervisor active; boot continues while hotspot is offline");

    ret = camera_init();
    if (ret != ESP_OK) {
        ESP_LOGE(TAG, "Camera init failed: 0x%x; restarting in 5 seconds", ret);
        vTaskDelay(pdMS_TO_TICKS(5000));
        esp_restart();
    }
    ret = camera_start();
    if (ret != ESP_OK) {
        ESP_LOGE(TAG, "Camera start failed: 0x%x; restarting in 5 seconds", ret);
        vTaskDelay(pdMS_TO_TICKS(5000));
        esp_restart();
    }
    s_camera_started = true;
    ESP_LOGI(TAG, "Camera %dx%d started", SW, SH);

    s_dist_mutex = xSemaphoreCreateMutex();
    s_video_meta_mutex = xSemaphoreCreateMutex();
    s_cap_timing_mutex = xSemaphoreCreateMutex();
    if (!s_dist_mutex || !s_video_meta_mutex || !s_cap_timing_mutex) {
        ESP_LOGE(TAG, "Shared mutex allocation failed");
        return;
    }

    bool mega_sr04_ready = false;
#if MEGA_SR04_ENABLED
    mega_sr04_ready = (mega_sr04_init() == ESP_OK);
    if (!mega_sr04_ready) {
        ESP_LOGW(TAG, "Mega USB HC-SR04 init failed (continuing without height reference)");
    } else {
        ESP_LOGI(TAG, "Mega USB HC-SR04 enabled: Mega D53 TRIG / D52 ECHO");
    }
#else
    ESP_LOGI(TAG, "Mega USB HC-SR04 disabled");
#endif

#if ACTUATOR_MOTION_ENABLED
    ret = actuator_init();
    s_actuator_ready = (ret == ESP_OK);
    if (!s_actuator_ready) {
        ESP_LOGW(TAG, "Actuator init failed: 0x%x (motion remains locked)", ret);
    }
#else
    // GPIO14 is currently C6 SDIO D0, while the legacy RR actuator plan also
    // used GPIO14. Do not initialize any actuator PWM until that physical pin
    // conflict and travel/position safeguards are resolved.
    ESP_LOGW(TAG, "Actuators safety-locked: legacy RR GPIO14 conflicts with C6 SDIO D0");
#endif

    init_gray_lut();
    ESP_LOGI(TAG, "RGB565->gray LUT ready (256 bytes, exact BT.601 arithmetic)");

    s_local_buf = heap_caps_aligned_alloc(64, SW * SH * 2, MALLOC_CAP_SPIRAM);
    s_gray_a = heap_caps_aligned_alloc(64, SW * SH, MALLOC_CAP_SPIRAM);
    s_gray_b = heap_caps_aligned_alloc(64, SW * SH, MALLOC_CAP_SPIRAM);
    s_write_gray = s_gray_a;
    s_send_gray = s_gray_b;
    s_frame_ready = xSemaphoreCreateBinary();
    s_buf_free = xSemaphoreCreateBinary();
    xSemaphoreGive(s_buf_free);

    jpeg_encode_engine_cfg_t jeng = {.intr_priority = 0, .timeout_ms = 1000};
    jpeg_new_encoder_engine(&jeng, &s_jpeg_enc);
    jpeg_encode_memory_alloc_cfg_t jmem = {.buffer_direction = JPEG_ENC_ALLOC_OUTPUT_BUFFER};
    s_jpeg_buf = (uint8_t *)jpeg_alloc_encoder_mem(JPEG_BUF_SIZE, &jmem, &s_jpeg_buf_sz);

    ESP_LOGI(TAG, "Buffers ready");

    // Keep the 87 ms RGB565→gray workload off CPU1: CPU1 is reserved for
    // the BNO085 UART ISR and high-priority parser.  The main JPEG/TCP loop
    // already runs on CPU0, so pin capture conversion to CPU0 as well rather
    // than starving UART reception during active video streaming.
    // Low-rate height reference task stays on CPU0; CPU1 remains reserved for
    // the UART-RVC ISR/parser.
    if (mega_sr04_ready) xTaskCreatePinnedToCore(mega_distance_mirror_task, "mega_dist", 3072, NULL, 2, NULL, 0);
    xTaskCreatePinnedToCore(capture_task, "cap", 8192, NULL, 5, NULL, 0);
    xTaskCreate(tcp_server_task, "tcp", 4096, NULL, 3, NULL);
    if (imu_is_ready())       xTaskCreate(imu_task, "imu", 8192, NULL, 4, NULL);
    // Priority 9 remains well below the UART parser (24). This independent
    // JSONL publisher must never participate in JPEG/frame timing or block
    // the RVC parser; a socket failure simply disconnects its client.
    if (imu_is_ready())       xTaskCreatePinnedToCore(imu_tcp_server_task, "imu_tcp", 4096, NULL, 9, NULL, 1);
    xTaskCreate(http_supervisor_task, "http_super", 4096, NULL, 3, NULL);

    vTaskDelay(pdMS_TO_TICKS(2000));
    // esp_log_level_set("*", ESP_LOG_NONE);  // 调试: 保持日志开启

    jpeg_encode_cfg_t enc_cfg = {
        .width = SW, .height = SH,
        .src_type = JPEG_ENCODE_IN_FORMAT_GRAY,
        .sub_sample = JPEG_DOWN_SAMPLING_GRAY,
        .image_quality = JPEG_QUALITY,
    };

    uint32_t fc = 0;
    uint32_t perf_count = 0;
    uint32_t perf_timing_samples = 0;
    uint32_t perf_timing_missed = 0;
    int64_t perf_t0 = esp_timer_get_time();
    int64_t acc_cap = 0, acc_cp = 0, acc_gray = 0, acc_enc = 0, acc_send = 0;

    while (1) {
        if (xSemaphoreTake(s_frame_ready, pdMS_TO_TICKS(5000)) == pdTRUE) {
            int64_t t_enc0 = esp_timer_get_time();
            uint32_t jpeg_size = 0;
            esp_err_t enc_ret = jpeg_encoder_process(s_jpeg_enc, &enc_cfg,
                                    s_send_gray, SW * SH,
                                    s_jpeg_buf, s_jpeg_buf_sz, &jpeg_size);
            int64_t t_enc1 = esp_timer_get_time();

            xSemaphoreGive(s_buf_free);

            bool sent = false;
            int64_t send_us = 0;

            if (enc_ret == ESP_OK && jpeg_size > 0 && s_client_sock >= 0) {
                int64_t t_send0 = esp_timer_get_time();
                uint32_t len_le = jpeg_size;
                bool ok = send_all(s_client_sock, &len_le, 4);
                if (ok) ok = send_all(s_client_sock, s_jpeg_buf, jpeg_size);
                int64_t t_send1 = esp_timer_get_time();

                if (!ok) {
                    close(s_client_sock);
                    s_client_sock = -1;
                } else {
                    sent = true;
                    send_us = t_send1 - t_send0;
                    int64_t ts = esp_timer_get_time();
                    uint32_t frame_id = 0;
                    if (xSemaphoreTake(s_video_meta_mutex, pdMS_TO_TICKS(10)) == pdTRUE) {
                        frame_id = ++s_video_frame_id;
                        s_jpeg_timestamp_us = ts;
                        s_video_jpeg_size = jpeg_size;
                        s_video_meta_valid = true;
                        uint32_t idx = s_ring_head;
                        s_meta_ring[idx].frame_id = frame_id;
                        s_meta_ring[idx].timestamp_us = ts;
                        s_meta_ring[idx].jpeg_size = jpeg_size;
                        s_ring_head = (s_ring_head + 1) % VIDEO_META_RING_SIZE;
                        if (s_ring_count < VIDEO_META_RING_SIZE) s_ring_count++;
                        xSemaphoreGive(s_video_meta_mutex);
                    } else {
                        // Frame ID must remain monotonic even if the HTTP
                        // video-meta endpoint briefly owns the mutex.
                        frame_id = ++s_video_frame_id;
                    }
                }
            }

            fc++;
            if (enc_ret == ESP_OK && jpeg_size > 0) {
                cap_timing_t timing_snap;
                if (xSemaphoreTake(s_cap_timing_mutex, pdMS_TO_TICKS(10)) == pdTRUE) {
                    timing_snap = s_cap_timing;
                    xSemaphoreGive(s_cap_timing_mutex);
                    acc_cap += timing_snap.capture_us;
                    acc_cp += timing_snap.copy_us;
                    acc_gray += timing_snap.gray_us;
                    perf_timing_samples++;
                } else {
                    perf_timing_missed++;
                }
                acc_enc += (t_enc1 - t_enc0);
                acc_send += send_us;
                perf_count++;
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

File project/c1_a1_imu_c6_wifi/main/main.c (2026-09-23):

/* C1-A1: BNO085 UART-RVC + real C6 SDIO/Wi-Fi; no camera/CSI/ISP/JPEG/TCP. */
#include <inttypes.h>
#include <stdbool.h>
#include <string.h>

#include "freertos/FreeRTOS.h"
#include "freertos/task.h"
#include "freertos/semphr.h"
#include "esp_log.h"
#include "esp_timer.h"
#include "esp_event.h"
#include "esp_netif.h"
#include "esp_wifi.h"
#include "nvs_flash.h"
#include "driver/uart.h"
#include "esp_heap_caps.h"

#define WIFI_SSID "MarsLander"
#define WIFI_PASS "mars2026"
#define RVC_UART UART_NUM_1
#define RVC_RX_PIN 3
#define RVC_BAUD 115200
#define RVC_PACKET_LEN 19
#define RVC_RX_BUFFER_SIZE (16 * 1024)

static const char *TAG = "C1_A1";
static SemaphoreHandle_t s_imu_mutex;
typedef struct {
    uint32_t valid;
    uint32_t timeouts;
    uint32_t checksum;
    uint32_t sync;
    int64_t last_ts_us;
    uint8_t last_index;
} imu_stats_t;
static imu_stats_t s_stats;
static volatile bool s_wifi_connected;

static int16_t le_i16(const uint8_t *p)
{
    return (int16_t)((uint16_t)p[0] | ((uint16_t)p[1] << 8));
}

static bool rvc_checksum_valid(const uint8_t packet[RVC_PACKET_LEN])
{
    uint8_t sum = 0;
    for (int i = 2; i < RVC_PACKET_LEN - 1; ++i) sum += packet[i];
    return sum == packet[RVC_PACKET_LEN - 1];
}

static void wifi_event(void *arg, esp_event_base_t base, int32_t id, void *data)
{
    if (base == WIFI_EVENT && id == WIFI_EVENT_STA_START) {
        ESP_LOGI(TAG, "C1-A1 Wi-Fi station started; C6 SDIO path is active");
    } else if (base == WIFI_EVENT && id == WIFI_EVENT_STA_DISCONNECTED) {
        s_wifi_connected = false;
        ESP_LOGW(TAG, "C1-A1 Wi-Fi disconnected; reconnecting");
        esp_wifi_connect();
    } else if (base == IP_EVENT && id == IP_EVENT_STA_GOT_IP) {
        s_wifi_connected = true;
        ip_event_got_ip_t *event = (ip_event_got_ip_t *)data;
        ESP_LOGI(TAG, "C1-A1 Wi-Fi IP=" IPSTR, IP2STR(&event->ip_info.ip));
    }
}

static void imu_uart_task(void *arg)
{
    uint8_t packet[RVC_PACKET_LEN];
    uint32_t timeout_streak = 0;
    while (true) {
        uint8_t byte;
        if (uart_read_bytes(RVC_UART, &byte, 1, pdMS_TO_TICKS(1000)) != 1) {
            timeout_streak++;
            if (xSemaphoreTake(s_imu_mutex, pdMS_TO_TICKS(5)) == pdTRUE) {
                s_stats.timeouts++;
                xSemaphoreGive(s_imu_mutex);
            }
            ESP_LOGW(TAG, "C1_A1_NO_UART seconds=%" PRIu32, timeout_streak);
            continue;
        }
        timeout_streak = 0;
        if (byte != 0xAA) {
            if (xSemaphoreTake(s_imu_mutex, pdMS_TO_TICKS(2)) == pdTRUE) {
                s_stats.sync++;
                xSemaphoreGive(s_imu_mutex);
            }
            continue;
        }
        if (uart_read_bytes(RVC_UART, &byte, 1, pdMS_TO_TICKS(20)) != 1 || byte != 0xAA) continue;
        packet[0] = packet[1] = 0xAA;
        if (uart_read_bytes(RVC_UART, packet + 2, RVC_PACKET_LEN - 2, pdMS_TO_TICKS(30)) != RVC_PACKET_LEN - 2) continue;
        if (!rvc_checksum_valid(packet)) {
            if (xSemaphoreTake(s_imu_mutex, pdMS_TO_TICKS(2)) == pdTRUE) {
                s_stats.checksum++;
                xSemaphoreGive(s_imu_mutex);
            }
            continue;
        }
        if (xSemaphoreTake(s_imu_mutex, pdMS_TO_TICKS(5)) == pdTRUE) {
            s_stats.valid++;
            s_stats.last_ts_us = esp_timer_get_time();
            s_stats.last_index = packet[2];
            xSemaphoreGive(s_imu_mutex);
        }
    }
}

static void stats_task(void *arg)
{
    while (true) {
        imu_stats_t stats = {0};
        if (xSemaphoreTake(s_imu_mutex, pdMS_TO_TICKS(20)) == pdTRUE) {
            stats = s_stats;
            xSemaphoreGive(s_imu_mutex);
        }
        ESP_LOGI(TAG,
                 "C1_A1_STATS valid=%" PRIu32 " idx=%u age_ms=%" PRId64
                 " timeout=%" PRIu32 " checksum=%" PRIu32 " sync=%" PRIu32
                 " wifi=%s heap=%u largest=%u",
                 stats.valid, stats.last_index,
                 stats.last_ts_us ? (esp_timer_get_time() - stats.last_ts_us) / 1000 : -1,
                 stats.timeouts, stats.checksum, stats.sync,
                 s_wifi_connected ? "up" : "down",
                 (unsigned)esp_get_free_heap_size(),
                 (unsigned)heap_caps_get_largest_free_block(MALLOC_CAP_8BIT));
        vTaskDelay(pdMS_TO_TICKS(1000));
    }
}

static void init_bno_uart(void)
{
    uart_config_t cfg = {
        .baud_rate = RVC_BAUD,
        .data_bits = UART_DATA_8_BITS,
        .parity = UART_PARITY_DISABLE,
        .stop_bits = UART_STOP_BITS_1,
        .flow_ctrl = UART_HW_FLOWCTRL_DISABLE,
        .source_clk = UART_SCLK_DEFAULT,
    };
    ESP_ERROR_CHECK(uart_param_config(RVC_UART, &cfg));
    ESP_ERROR_CHECK(uart_set_pin(RVC_UART, UART_PIN_NO_CHANGE, RVC_RX_PIN,
                                 UART_PIN_NO_CHANGE, UART_PIN_NO_CHANGE));
    ESP_ERROR_CHECK(uart_driver_install(RVC_UART, RVC_RX_BUFFER_SIZE, 0, 0, NULL, 0));
    uart_flush_input(RVC_UART);
    ESP_ERROR_CHECK(xTaskCreatePinnedToCore(imu_uart_task, "c1_imu_uart", 4096, NULL, 10, NULL, 1) == pdPASS ? ESP_OK : ESP_ERR_NO_MEM);
}

static void init_c6_wifi(void)
{
    ESP_ERROR_CHECK(esp_netif_init());
    ESP_ERROR_CHECK(esp_event_loop_create_default());
    ESP_ERROR_CHECK(esp_event_handler_instance_register(WIFI_EVENT, ESP_EVENT_ANY_ID, &wifi_event, NULL, NULL));
    ESP_ERROR_CHECK(esp_event_handler_instance_register(IP_EVENT, IP_EVENT_STA_GOT_IP, &wifi_event, NULL, NULL));
    esp_netif_create_default_wifi_sta();
    wifi_init_config_t init_cfg = WIFI_INIT_CONFIG_DEFAULT();
    ESP_ERROR_CHECK(esp_wifi_init(&init_cfg));
    wifi_config_t config = {.sta = {.ssid = WIFI_SSID, .password = WIFI_PASS, .threshold.authmode = WIFI_AUTH_WPA2_PSK}};
    ESP_ERROR_CHECK(esp_wifi_set_mode(WIFI_MODE_STA));
    ESP_ERROR_CHECK(esp_wifi_set_config(WIFI_IF_STA, &config));
    ESP_ERROR_CHECK(esp_wifi_start());
    ESP_ERROR_CHECK(esp_wifi_connect());
}

void app_main(void)
{
    ESP_LOGI(TAG, "C1-A1 BEGIN: IMU + C6 SDIO/Wi-Fi ONLY; camera is not linked or initialized");
    ESP_ERROR_CHECK(nvs_flash_init());
    s_imu_mutex = xSemaphoreCreateMutex();
    if (!s_imu_mutex) abort();
    init_bno_uart();
    init_c6_wifi();
    xTaskCreate(stats_task, "c1_stats", 4096, NULL, 4, NULL);
}
